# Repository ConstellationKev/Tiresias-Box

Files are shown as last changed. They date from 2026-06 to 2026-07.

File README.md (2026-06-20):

# Tiresias' Box

A portable, dynamic braille translator for both English and Chinese that incorporates an idea for changeable braille never been presented before. This is the first ever braille actuator cell that uses rotating CAM mechanisms to change the positions of the braille dots.
* Demo Video: [https://youtu.be/Fnp10YjDIxU?si=KQs606D453VQbDC9](https://youtu.be/Fnp10YjDIxU?si=KQs606D453VQbDC9)

Front  
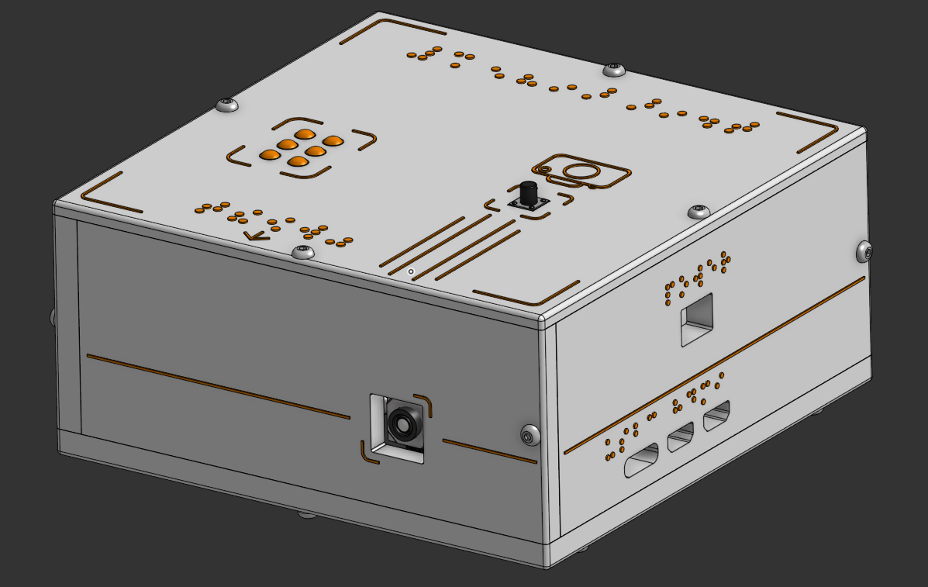
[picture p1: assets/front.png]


Back  
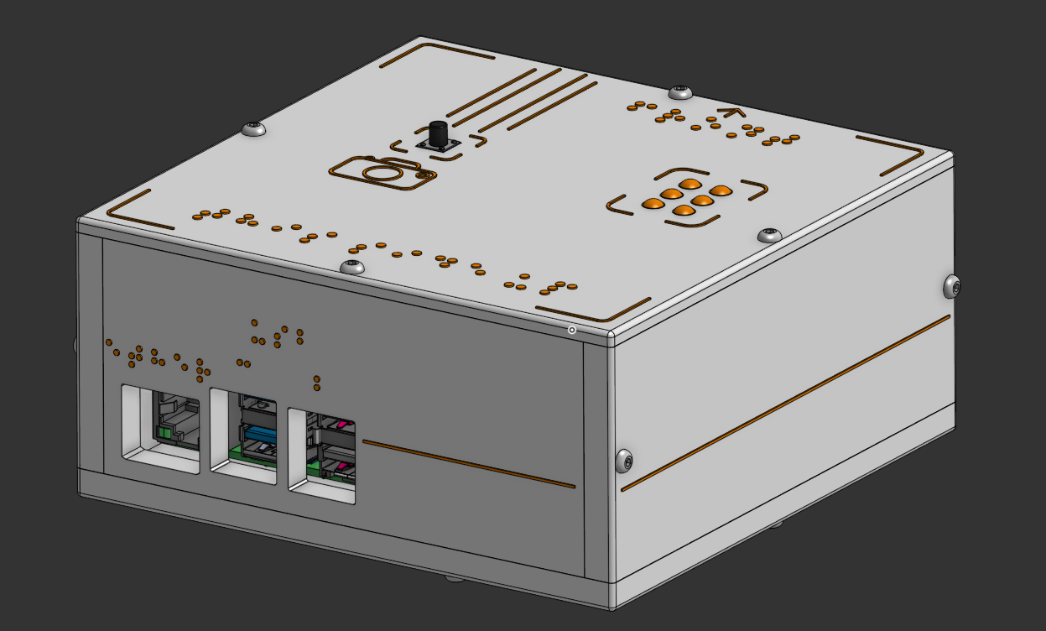
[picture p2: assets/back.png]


# Overview

This is a fun box that has a feature to take pictures of where its camera is pointing and then extracts the English or Chinese text it sees in real life to translate into braille in the braille area on top of the box. This box is only about 12 cm x 12 cm x 5.5 cm large and is very light. The white and orange design of the box was inspired by FRC 118 Robonauts, the team that got me into the white and orange design colors. The extremely easy assembly makes this a very beginner friendly project that even me, a complete beginner, could build with ease.

# Highlights

* **Custom Rotating CAM Braille Actuators**: The heart of this project, which are two custom made independent rotating CAMs stacked on top of each other which is able to change the orientations of the pins to be able to output every letter in the braille alphabet.  
* **Nicely-Scaled Braille Pins**: These small 3D printed custom pins are always in direct contact with the CAMs and are driven by nature’s most natural force, gravity. These pins are extremely light and gravity is all they need to be able to move with the CAM. They are also a good size to be felt with a single finger.  
* **Autofocus Raspberry Pi Camera Module 3**: Camera that does not require manual focusing and can take pictures of its surroundings in high detail and resolution to help with text extraction and analysis.  
* **Raspberry Pi 5**: The Raspberry Pi and the fact that all the mechanisms that drive that this project are connected to it makes this project very customizable. The Raspberry Pi allows for extremely fast live processing and analysis as well as file storage and servo control. Other people wanting to make this project can add onto the preexisting code as well as connect other mechanisms to widen the capabilities of this box.  
* **Blind Friendly** **Usage**: All of the ports and other important parts of the box are labeled with real braille which can be read by blind people. Although this box is not the most practical design currently, it is still able to be used completely by blind people.
* **Both Chinese Simplified And English Support**: This little box is able to both extract English text as well as Chinese Simplified characters and translating it to English, covering two of the biggest languages in the world.  

Custom braille CAM actuators  
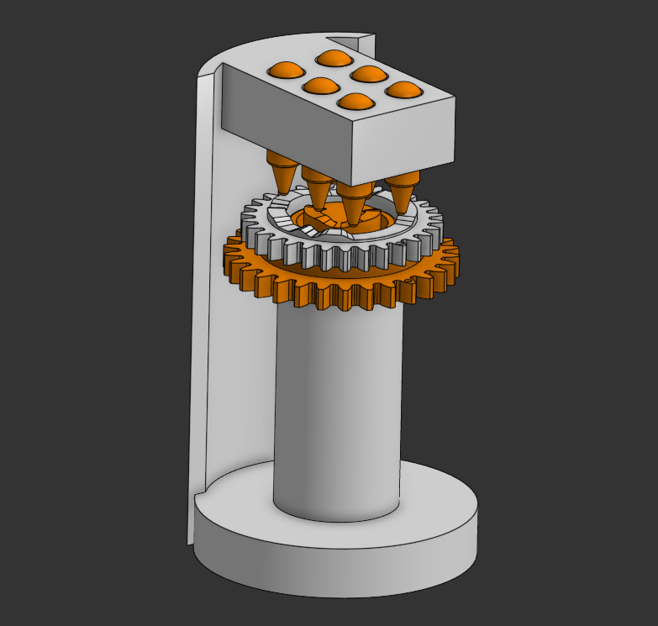
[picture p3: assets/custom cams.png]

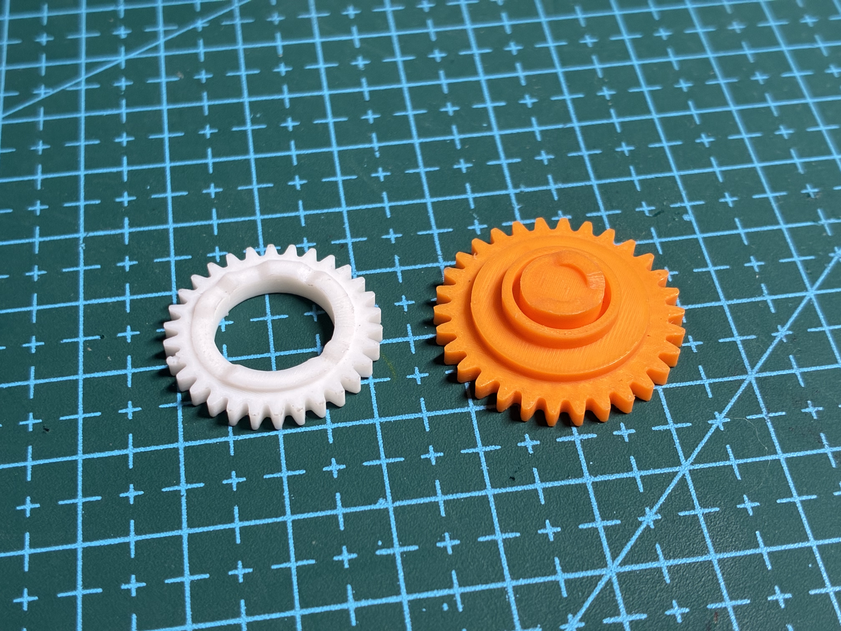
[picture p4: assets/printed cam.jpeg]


# Why?

Let’s first talk about why this is called Tiresias' Box. If you are a Greek mythology fanatic like I am, you would instantly recognize the all-knowing, blind prophet Tiresias. This person is an absolute legend and is one of the most knowledgeable Greek mythology characters. I wanted to create a project to help the blind as this disability should not be a limiting factor for their potential to do great things, just like Tiresias. 

This project helps solve the real world problem of blind people not being able to read words in the world, whether that is street signs, a restaurant menu, or something in the newspaper. It uses a camera and computer vision to restore their sight, translating the words they are unable to see into a format they are very familiar with, braille. Making this project as small as possible also helps take one step closer to this being a practical, portable device that people can bring wherever they go, actually helping them in the real world.

However, some people may have many questions about this project such as why not just use speakers? Personally, my answer to that is that speaking out words in the real world already exist and are more efficient than ever. Almost all phones have apps that can do this better than any personal project and they can even connect any external headphones to the phones.

Another question people may ask is how is this different from existing dynamic braille actuators? This is my unique approach to dynamic braille which incorporates CAM mechanisms to change the braille rather than some existing designs such as using a separate motor for every single braille dot or electromagnetic actuators. Some of the main goals that I hoped to accomplish is using as few motors as possible and making the braille dots move both smoothly but also stay rigidly in place when people’s fingers are moving over them and pressing down on them. Some electromagnetic designs are not strong enough to hold up the force of people’s fingers on the braille or it is not too energy efficient. I thought of a custom rotating CAM mechanism that essentially has rises and drops in the CAM that drives the pin's braille pins to move up and down. The braille pins are also in constant contact with the CAM due to their light weight and force due to gravity so they will have more than enough normal force to withstand people’s fingers. Additionally, the servos that drive these CAMs do not need to use any power to help keep the pins where they should be, they are already propped up by the CAM's geometry. Furthermore, I separated the CAMs into an inner and outer CAM which lessened the amount of motors to drive the braille down to two servos to control the movement of six pins. This is what makes this design different from all the current designs.

Lastly, I love computer vision. I always do the computer vision algorithms on my robotics team and I have always found its applications endless and all the different parts of it super intriguing. If I do a project, it would not be mine if it did not include any computer vision 🙂.

# How To Use

This project is extremely easy to use, only consisting of a button that you would need to press and the code ran from the Raspberry Pi. If you did the run script upon power up command from the software setup steps, this project would essentially be similar to any project you would find for sale. However, if you didn’t do that step, you would need to run the main.py file in the firmware folder in the Raspberry Pi.

Do these steps after you have properly assembled and set up the box please. They will not work otherwise.

1. Plug the USB-C power source into the Raspberry Pi through the USB-C port opening and the 5V power source into the PCA9685 through the opening to the top right of the USB-C opening.  
2. Boot up the Raspberry Pi and wait for about 5 seconds for the camera to start up and adjust to its surroundings and the braille to move to its initial positions, and you are ready to use it\!  
3. Press the button to take a picture of whatever is in front of it and the dynamic braille will automatically change depending on the letters that it sees. It will go in order from left to right to the letters/words it sees, first displaying the leftmost letter, then changing to the next letter, and so on until all the text is displayed. Each character will stay for about 2 seconds until the next one is displayed.  
4. After all the text is displayed and the braille is no longer changing, you will be able to take another photo of different text and it will show that text. No need to worry about memory of the photos as after each translation, the photos that you have taken will be deleted to save storage. 
5. Press and hold the button for about 3 seconds and the box will be able to toggle translate from Chinese to English or purely English for the photos that the user takes. The braille that is displayed will be in English. Press and hold the button to switch the detection model. The inital model will only extract English; the next toggle will be able to translate.
5. Press and hold the button for about 6 seconds and the code will stop and the camera will power off. Make sure you do this every time to ensure the code stops properly and the camera powers off nicely. Directly cutting the power may wear the Pi and the camera unnecessarily and is bad practice.  
6. After doing so, you can power off your Raspberry Pi and unplug the external power supplies.

Where the external power supplies should be plugged in  
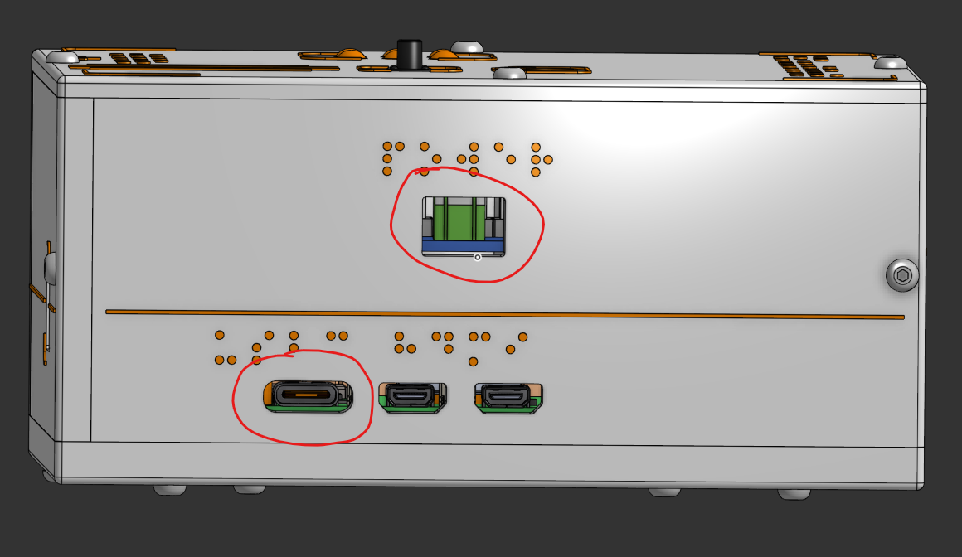
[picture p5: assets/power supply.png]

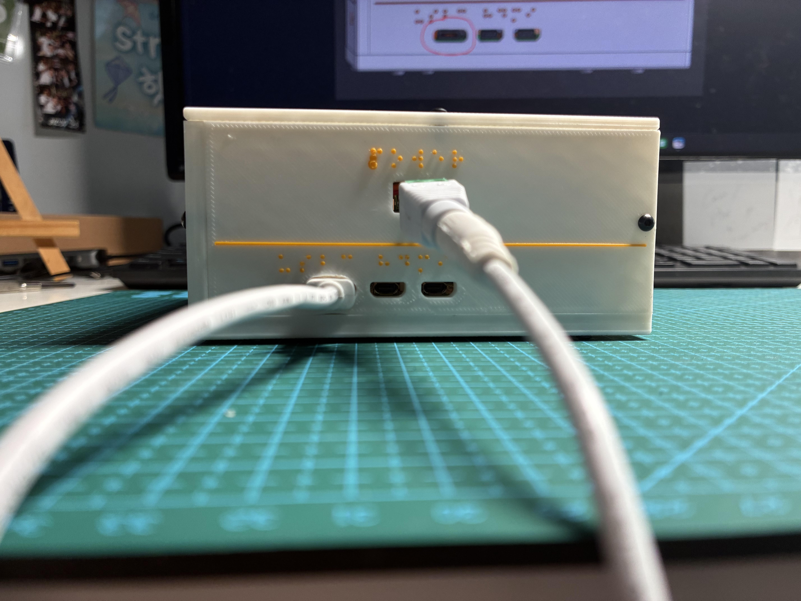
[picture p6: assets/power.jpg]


# Hardware

| Component | Notes |
| :---- | :---- |
| Raspberry Pi 5 | For running the code, storing files, live computer vision analysis, being the brain of the whole project. |
| Adafruit PCA9685 Servo Driver | Running servos separately of the Raspberry Pi to lessen its load and prevent the risk of frying the Pi due to the servos. |
| Raspberry Pi 27W USB-C PSU | For powering the Raspberry Pi |
| 5V 2A power supply | For powering the PCA9685 |
| Raspberry Pi Camera Module 3 Standard \- 12MP Autofocus | Autofocus camera that is able to take high resolution photos for efficient computer vision analysis. |
| SG90 9g Digital Micro Servo | To move the CAM mechanisms. |
| 6mm 2 Pin Panel PCB Momentary Tactile Tact Push Button | To control when to take pictures, change the braille, and turn off the code. |
| 16GB+ Micro SD Card | Store files and the Raspberry Pi OS. |

You can find more detailed buying links and prices of these components as well as other materials not listed here in the [Bill Of Materials](/BOM/BOM.csv) below.
|Material |Qty|Units |Buying Link (Accounts for quantity) |Cost (Accounts for shipping)|Notes |
|---|---|---|---|---|---|
|Raspberry Pi 5 4GB RAM |1  |Each  |https://www.microcenter.com/product/673712/raspberry-pi-5 |$109.99 |I can pay out of pocket for this if it is unable to be approved for funding.|
|Raspberry Pi Camera Module 3 Standard - 12MP Autofocus |1  |Each  |https://www.amazon.com/Raspberry-Pi-Camera-Module/dp/B0BRY6MVXL/ |$43.89 | |
|Raspberry Pi 5 FPC Camera Cable |1  |Each  |https://www.microcenter.com/product/671933/raspberry-pi-5-camera-cable-300mm |$2.99 | |
|Adafruit 16-Channel 12-bit PWM/Servo Driver - I2C interface - PCA9685|1  |Each  |https://www.microcenter.com/product/613661/adafruit-industries-16-channel-12-bit-pwm-servo-driver|$14.95 | |
|20 AWG Silicone Hookup Wires (2 Colors) |2  |Wires |https://www.amazon.com/Silicone-Electrical-Core-Flexible-Strands/dp/B0B9JCXN9M/ |$5.88 | |
|Female DC Power adapter - 2.1mm jack to screw terminal block |1  |Each  |https://www.amazon.com/ALITOVE-100-240V-Replacement-Security-Raspberry/dp/B0BVHQKNS6/ |$9.99 | |
|5V 2A (2000mA) switching power supply - UL Listed |1  |Each  |Same as above ^ |$0.00 |Included in above price |
|Raspberry Pi 27W USB-C PSU |1  |Each  |https://www.microcenter.com/product/671926/raspberry-pi-27w-usb-c-psu-white?src=raspberrypi |$11.99 | |
|6mm 2 Pin Panel PCB Momentary Tactile Tact Push Button |1  |Each  |https://www.amazon.com/MakerSpot-Momentary-Extension-Breadboard-Friendly/dp/B01J9KO7DC |$7.99 | |
|SG90 9g Digital Micro Servo |2  |Servos|https://www.amazon.com/Micro-Miuzei-Servos-Arduino-Airplane/dp/B0FJQZSFMS?th=1 |$8.44 | |
|M2.5 Screws + Nuts Kit |1  |Each  |https://www.amazon.com/binifiMux-280pcs-Button-Socket-Assortment/dp/B09CPDVYB7/ |$9.99 | |
|M2 Screws + Nuts Kit |1  |Each  |https://www.amazon.com/QOOSIKICC-Assortment-Socket-Washers-Machine/dp/B0DDXZH9L2/ |$7.58 | |
|Soldering Kit |1  |Each  |https://www.amazon.com/Soldering-soldering-solder-adjustable-temperature/dp/B09DY7CCW5/ |$9.99 |Self-sourced, I already own this so I don't need extra funding for this. |
|Jumper Wires F-F |4  |Wires |https://www.microcenter.com/product/618773/inland-30cm-40-pin-f-f-jumper-wire |$2.99 | |
|16GB Micro SD Card with Adapter |1  |Each  |https://www.amazon.com/SanDisk-Ultra-MicroSDHC-Memory-Adapter/dp/B00KNSAIVU/ |$26.89 |Self-sourced, I already own this so I don't need extra funding for this. |
|Base 3D Part |1  |Each  |N/A |$1.65 |Self-sourced, I already own this so I don't need extra funding for this. |
|Braille Pin 3D Part |6  |Each  |N/A |$0.06 |Self-sourced, I already own this so I don't need extra funding for this. |
|Close Wall 3D Part |1  |Each  |N/A |$0.44 |Self-sourced, I already own this so I don't need extra funding for this. |
|Far Wall 3D Part |1  |Each  |N/A |$0.44 |Self-sourced, I already own this so I don't need extra funding for this. |
|Inner Cam Servo Gear 3D Part |1  |Each  |N/A |$0.07 |Self-sourced, I already own this so I don't need extra funding for this. |
|Inner Cam 3D Part |1  |Each  |N/A |$0.04 |Self-sourced, I already own this so I don't need extra funding for this. |
|Left Wall 3D Part |1  |Each  |N/A |$0.45 |Self-sourced, I already own this so I don't need extra funding for this. |
|Long Spacer 3D Part |4  |Each  |N/A |$0.04 |Self-sourced, I already own this so I don't need extra funding for this. |
|Outer Cam Servo Gear 3D Part |1  |Each  |N/A |$0.05 |Self-sourced, I already own this so I don't need extra funding for this. |
|Outer Cam 3D Part |1  |Each  |N/A |$0.02 |Self-sourced, I already own this so I don't need extra funding for this. |
|Right Wall 3D Part |1  |Each  |N/A |$0.47 |Self-sourced, I already own this so I don't need extra funding for this. |
|Roof 3D Part |1  |Each  |N/A |$0.77 |Self-sourced, I already own this so I don't need extra funding for this. |
|Upper Mounting Plate 3D Part |1  |Each  |N/A |$0.13 |Self-sourced, I already own this so I don't need extra funding for this. |
|Taxes (in Fremont, California) |N/A|N/A |N/A |$28.51 |I don't need extra funding for this, I can pay this. |
| | | |Total Cost: |$306.69 | |
| | | |Note: Everything is bought with Amazon and Microcenter which has free shipping | | |

# About EasyOCR and Deep Translator

These are the two main Python libraries that I used in my project and are also integral parts of many other everyday applications. EasyOCR is a library that runs Optical Character Recognition which often built on neural networks to help detect text in real life, and then convert it to the string characters that we see on our computers. This software has been around for some time and is used for the text extraction for scanning documents on our phones, finding text in photos, and much more. In my project, the library EasyOCR is dircetly able to be used in Python and it utilizes PyTorch which is one of the biggest machine learning frameworks for Python currently. Every time the code runs, EasyOCR creates a model based on certain parameters to help you detect text. Due to the constraints for Raspberry Pi (yes, even this had constraints), my idea of being able to translate both English and Chinese using two different reader models was not feasible since a model consumes a lot of RAM each (we're saying from 1-3GB spikes) and I don't have much. Therefore, I was able to combine these two languages into a single model, as well as use a quantized model (using 8-bit integers for optimizing how much numerical precision the model outputs) to reduce the latency and improve the processing speed and efficiency. Since the Raspberry Pi is mainly using CPU for processing, the model also supports that and using a quanitized model helps with smaller RAM and CPU processing; it initially uses GPU and VRAM but Raspberry Pi does not support this. This model is essentially a neural network that runs every time for a image; downloading this model alone also takes up some storage and uses RAM, but it is less than actually running processing in the model. Well, if that isn't enough, let's introduce Deep Translator. This library allows us to use multiple different translation API clients such as Google Translate, which was used in this project. If there are any RAM concerns about this library, it does not do a lot of heavy lifting like the computer vision OCR pipelines above and it does use cloud clients which makes its processing even lighter. Therefore, its RAM usage is almost negligible and the RAM can be focused on running OCR. Both these libraries are integral parts of my project and it would not be possible without them. Please check out their documentation, they are genuinely so interesting and I hope you will find them useful in many of your future projects as well.
EasyOCR: [https://www.jaided.ai/easyocr/](https://www.jaided.ai/easyocr/), here's also the [github repo](https://github.com/JaidedAI/EasyOCR)
Deep Translator: [https://deep-translator.readthedocs.io/en/latest/](https://deep-translator.readthedocs.io/en/latest/)

# Assembly instructions

Make sure to finish the [software setup instructions](resources/software_setup.md) before continuing onto the [hardware setup instructions](resources/hardware_setup.md). You can find the same [wiring diagram](resources/wiring%20diagram.jpg) in the resources folder.   
Just to clarify a few things, for the PCA9685, the ground wire goes to the ground pin on the Raspberry Pi, the SCL wire goes to the SCL pin, the SDA wires goes to the SDA pin, and the VCC wire goes to the 3.3v pin.  
The button’s wires can be routed in any way to the GPIO5 and the ground pin next to it.

Wiring Diagram  
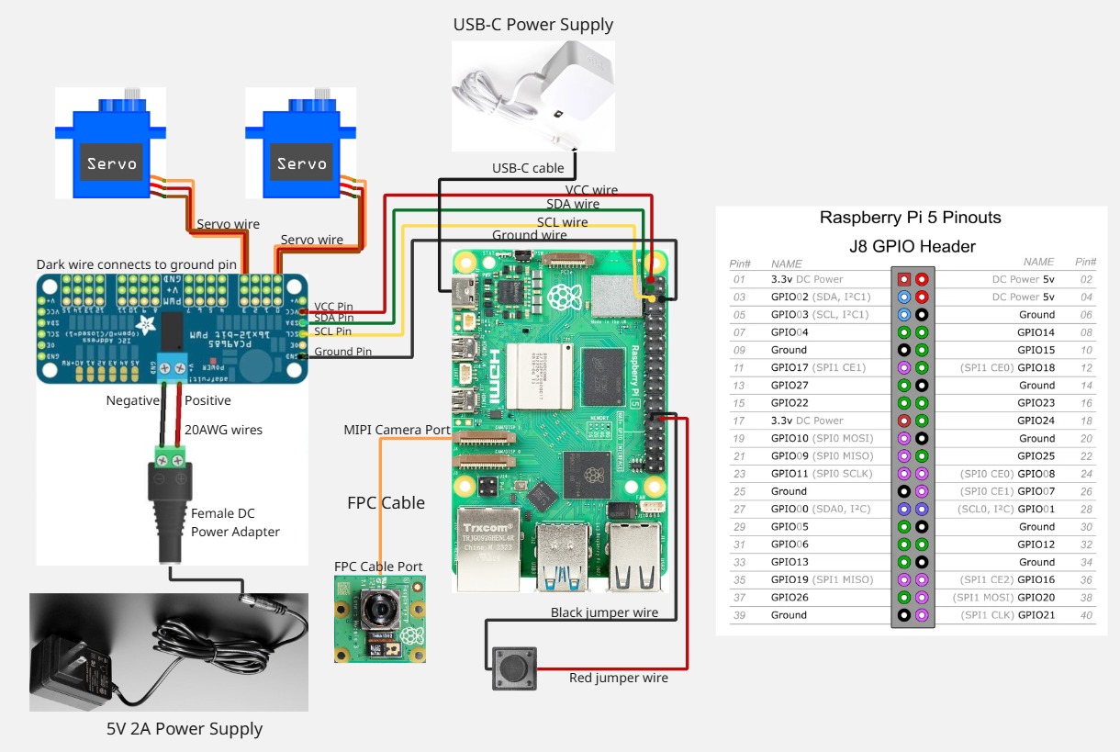
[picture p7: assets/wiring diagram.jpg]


# V1 Testing

Testing for proof of concept:


# Credits

All 3D Models cadded with Onshape.

The incredible YouTube videos that taught me along the way:

* [https://www.youtube.com/watch?v=GwpSpOwvx9Y\&t=1s](https://www.youtube.com/watch?v=GwpSpOwvx9Y&t=1s)  
* [https://www.youtube.com/watch?v=-x2EEIUMm6A](https://www.youtube.com/watch?v=-x2EEIUMm6A)  
* [https://www.youtube.com/watch?v=XPpw5P6AoEA](https://www.youtube.com/watch?v=XPpw5P6AoEA)  
* [https://www.youtube.com/watch?v=w-4V\_q8XWtk](https://www.youtube.com/watch?v=w-4V_q8XWtk)  
* [https://www.youtube.com/watch?v=Gl9HS7-H0mI](https://www.youtube.com/watch?v=Gl9HS7-H0mI)

# The Future

Currently, my project requires the box to be upright since it relies on the pin’s light weight and gravity for the CAM to move the braille pins. The pins are also able to be switched out easily by just plucking them out of the holes. However, in the future, I would want the box to be able to work in every single orientation, even when upside down. This made me think to either use very small springs or even make them magnetic to the CAM. I have researched these ideas and the small springs were very difficult to find for my tiny pins and the magnetic CAM is not possible since I only have a plastic 3D printer and no CNC or laser cutter.

I also would like the whole box to be even smaller and compact to make it even more portable and practical for every day use.

I would also like to make the CAM and pins even smoother. Right now, even using a 0.2 mm nozzle and the thinnest slicer settings, there are still layer lines on my prints. I want to eliminate those entirely in the future using some of those more advanced ways to get these custom 3D parts.

# Contact

* Discord: eclipse\_c  
* Email: kevinkunzhong@gmail.com

# Zine
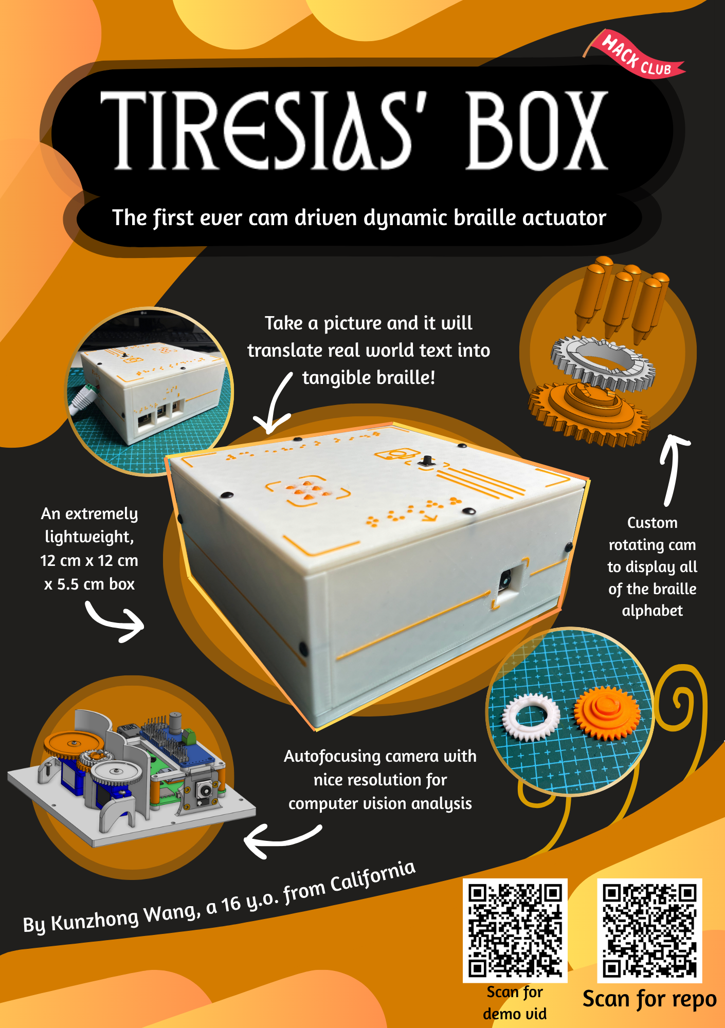
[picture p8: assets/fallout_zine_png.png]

The [PDF version](resources/fallout%20project%20zine.pdf) can be found in the resources folder.

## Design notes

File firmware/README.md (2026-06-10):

# Tuning Positions
A lot of this code requires to manually tune positions of the servos based on the braille pin positions and the gear positions. I have put everything that requires to be tuned as a value of 0 for now and they will be tuned when parts arrive for actual building.

Tuning only needs to be done once as the servo models will be the same for the project so other people building this project will have the same degrees of rotation. The hardware setup python file will set the servos to the inital positions so that each similar project to this will be set up the same way. So, this code and to-be-tuned postions will be able to be used for any project like this one.

Additionally, other things that also need to be tuned are the delay and timing thresholds for the servo movements

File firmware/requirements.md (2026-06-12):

# Requirements
## Libraries Required to Run Code:
1. `adafruit_servokit`
    - Import by typing this command into Raspberry Pi Terminal: `sudo pip3 install adafruit-circuitpython-servokit`
    - Command to fix externally-managed-environment error: `sudo rm /usr/lib/python3.11/EXTERNALLY-MANAGED`
2. `time`
3. `easyocr`
    - Import by typing this command into Raspberry Pi Terminal: `sudo pip3 install easyocr`
    - Command to fix externally-managed-environment error: `sudo rm /usr/lib/python3.11/EXTERNALLY-MANAGED`
4. `picamera2`
    - Included with the Raspberry Pi OS
5. `libcamera`
    - Included with the Rapsberry Pi OS
6. `os`
7. `gpiozero`
8. `deep_translator`
    - Import by typing this command into Raspberry Pi Terminal: `sudo pip3 install deep-translator`

## Enough Storage For Running things
Make sure your SD card can hold your Raspberry Pi OS as well as be able to hold the code and image files. The OS is about 8GB so make sure to find an SD card to be able to do other things as well. Anything above 8GB should be fine.

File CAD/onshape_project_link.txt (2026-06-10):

https://cad.onshape.com/documents/8ab90068d8e5494ca445e30f/w/5666b0c0f4cc86aaf66cce07/e/73d03172aee4f037fc1a40dc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

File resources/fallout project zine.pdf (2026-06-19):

## The first ever cam driven dynamic braille actuator

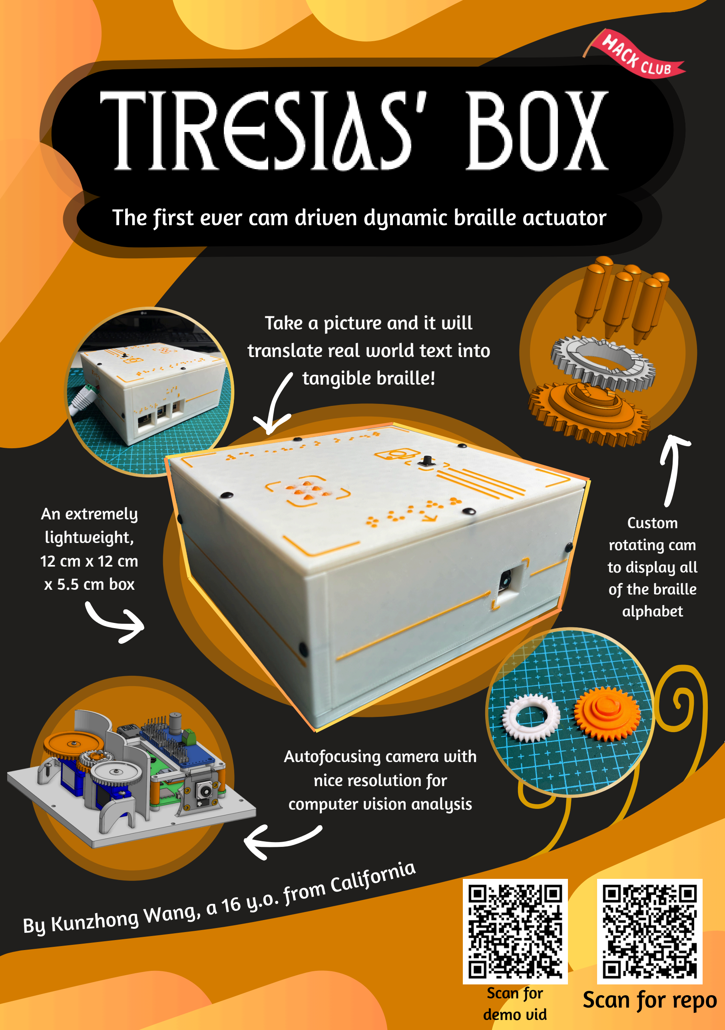
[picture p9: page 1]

Take a picture and it will translate real world text into tangible braille!

## Scan for repo

### By Kunzhong Wang, a 16 y.o. from California

Autofocusing camera with
nice resolution for
computer vision analysis

An extremely
lightweight,

### 12 cm x 12 cm

x 5.5 cm box

Custom
rotating cam
to display all
of the braille
alphabet

Scan for
demo vid

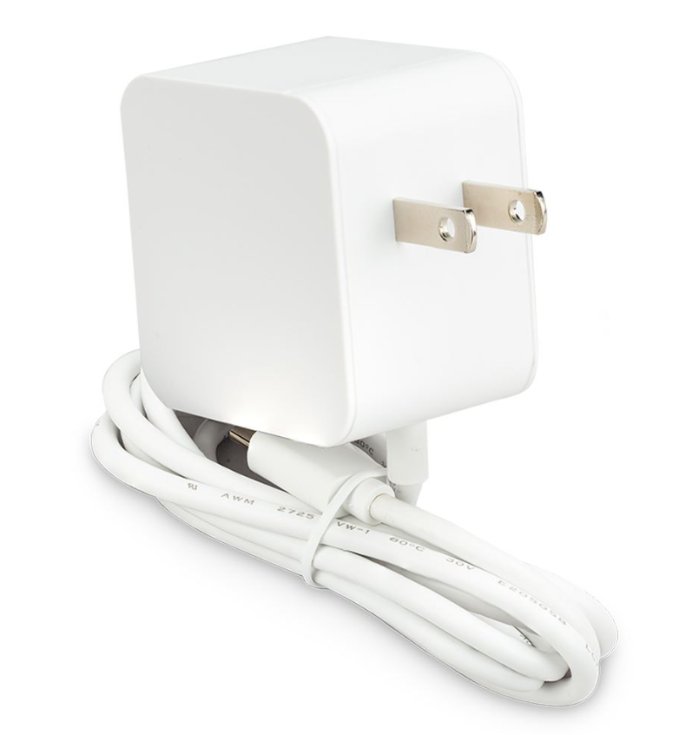
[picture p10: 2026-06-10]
resources/reference images/white USB-C power supply.png

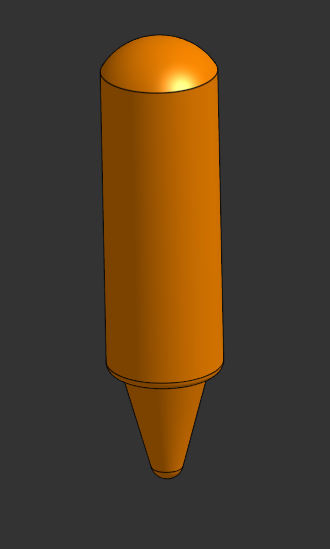
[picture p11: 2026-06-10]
resources/reference images/braille pin.png

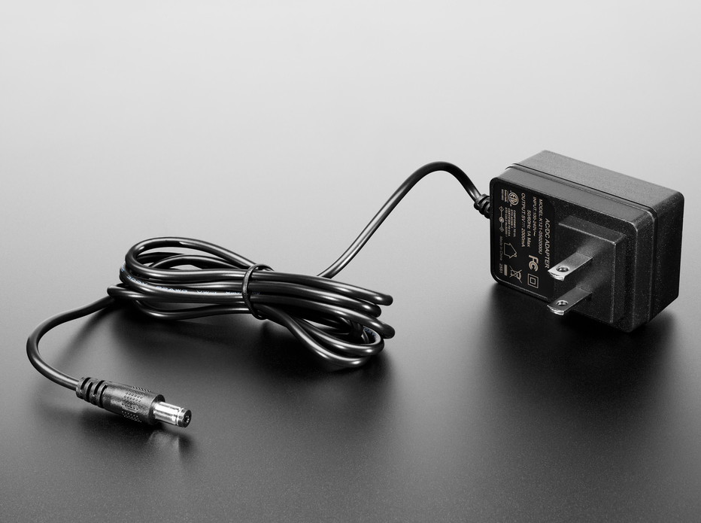
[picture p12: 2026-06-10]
resources/reference images/black 5V power supply.png

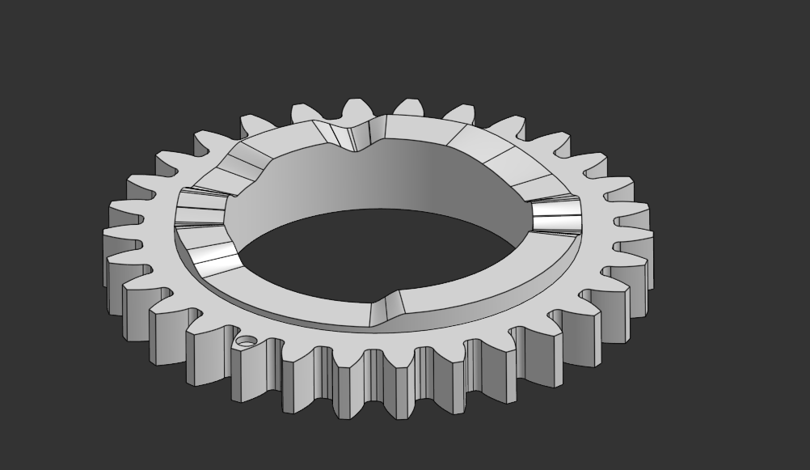
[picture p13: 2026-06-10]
resources/reference images/outer cam.png

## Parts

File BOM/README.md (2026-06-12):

# BOM Notes
## Why Certain Parts?
1. I chose the Raspberry Pi 5 because it only costs $9 more than the Raspberry Pi 4 and is the newest version. 4GB RAM was due to the research I did that asked for live computer vision analysis using tools like OpenCV and OCR. It was slightly on the lower end of the RAM many people suggested but it should be fine to run my CV applications, as well as all the other things in the code. I also read the docs and researched about Raspberry Pi Zero 2 W but their biggest bottleneck is the RAM and I need more RAM to run OCR, file managing, controlling servos, running the script, all live. I don't know what else I can use. I also don't know how to make my own PCB (but will definitately learn in the near future!) and this was suggested as the most beginner friendly way to manage and operate my project since it is essentially like a computer which I can code on. If this cannot be approved for funding, I am willing to pay out of pocket since changing will require a ton of tweaking for the entire project and just a lot of hours.
- Note: Here is a website I used for my research on using easyocr / OCR with my project and I tried to make things as cheap as possible for myself. https://www.llamaindex.ai/glossary/what-is-easyocr. The requirements are found in the System Requirements and Dependencies section. Raspberry Pi 5 with the minimum 4GB RAM is one of the few options that work within these specs.
- Please also read the About EasyOCR and Deep Translate section in the main [README](../README.md)
2. The Raspberry Pi Camera Module 3 was chosen because of its relatively high image quality as well as ability to autofocus. My project requires the camera to be able to detect and analyze text that appears in real life so having higher quality is a must. Autofocus is also a great feature since the people should not need to manually focus the camera; I also don't know how they would since they are blind.
3. The Adafruit PCA9685 is needed since many people suggested it is not good practice to run servos as well as a camera and doing live analysis using scripts on the Raspberry Pi all at once. This allows servos to run separately and not put any load on the Pi, which lowers the risk of frying it.
4. The push button was chosen since most buttons I found are for breadboards and this one can be directly plugged into the Raspberry Pi which helps a beginner a lot.

## Why Certain Buy Links?
Most of these buy links are to materials that are more in quantity that I need but I genuinely tried to find the least and cheapest options online.
1. The 20 AWG wires on Amazon were the least length I could find online since most vendors sell by tons of feet but I don't need that much. This is the least I can find for two colored wires.
2. The Push Button also comes in a pack of 5 on Amazon but I could not find any cheaper and singular selling buttons online. Most buttons I find either come in even larger packs or do not contain two wires to connect to the Raspberry Pi. 5 pack is least I can find.
3. The SG90 servos on Amazon are the digital ones that I need for precise movement but the least pack I can find them in is a pack of 3 when I only need 2. I tried finding packs of two online for digital servos but they are either very poorly reviewed or even more expensive than this 3 pack or they don't mention that they are digital.
4. The same situation for the jumper wires as the 20AWG hookup wires.
5. For the screws + nuts kits, I don't have any srews and stuff at home so this is the first time getting these kits. Other kits online are are either too expensive or do not contain the lengths of screws I need. This is also like an investment for my future projects so I don't need to buy any more screws.

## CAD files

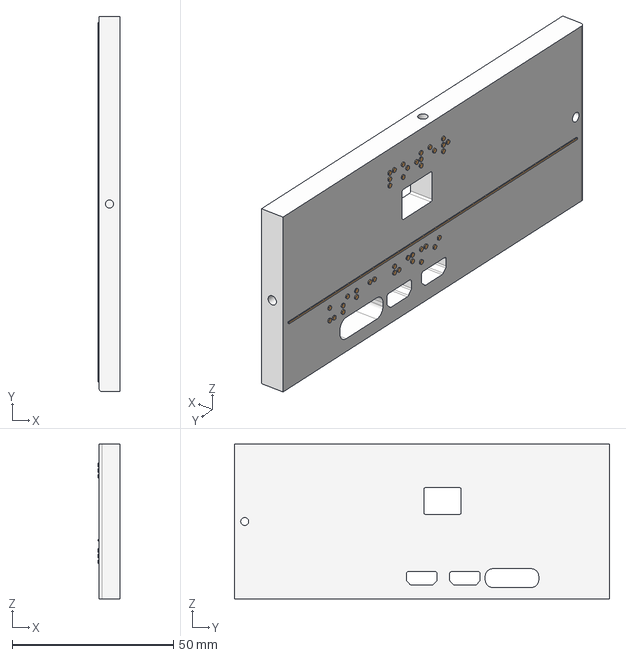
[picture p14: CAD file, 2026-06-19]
CAD/STEPs/left wall.step
6.80 x 116.5 x 48.1 mm

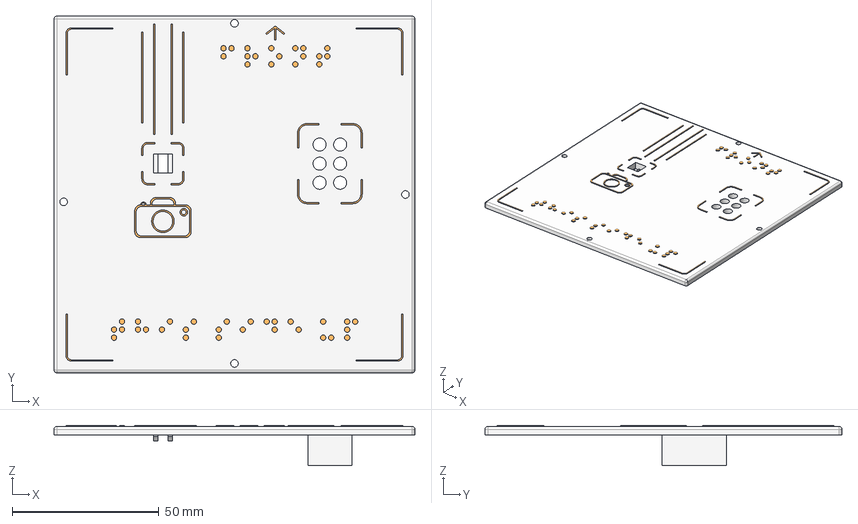
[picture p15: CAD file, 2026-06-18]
CAD/STEPs/roof.step
122.8 x 121.5 x 13.6 mm

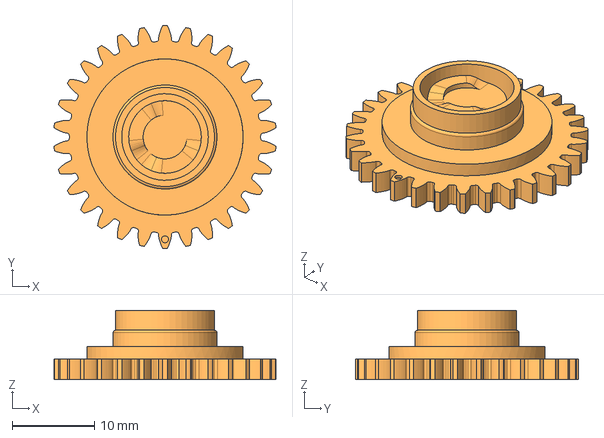
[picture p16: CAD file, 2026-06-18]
CAD/STEPs/inner cam.step
27.0 x 27.1 x 8.40 mm

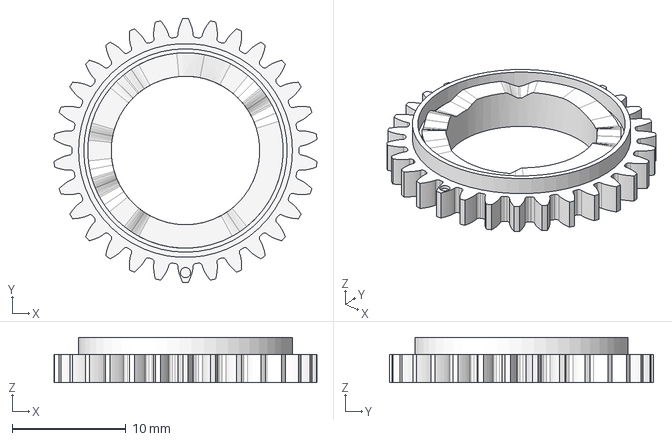
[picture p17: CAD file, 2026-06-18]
CAD/STEPs/outer cam.step
23.1 x 23.2 x 4.00 mm

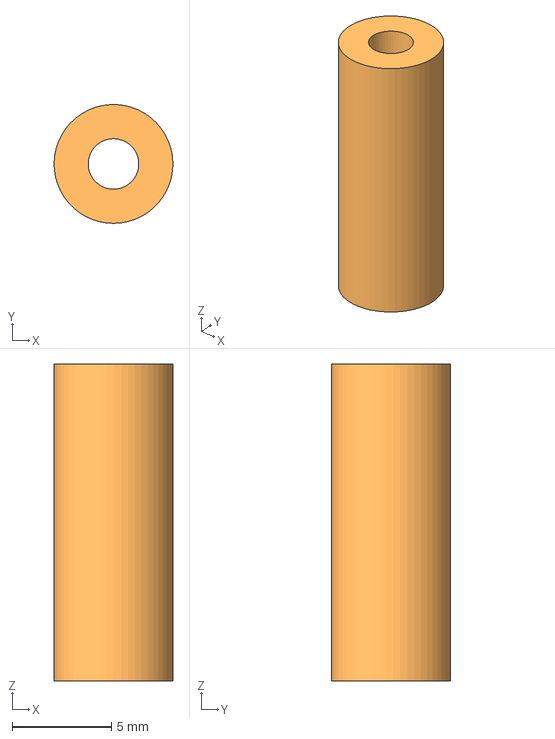
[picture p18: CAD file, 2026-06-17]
CAD/STEPs/long spacer 2.step
6.00 x 5.99 x 16.0 mm

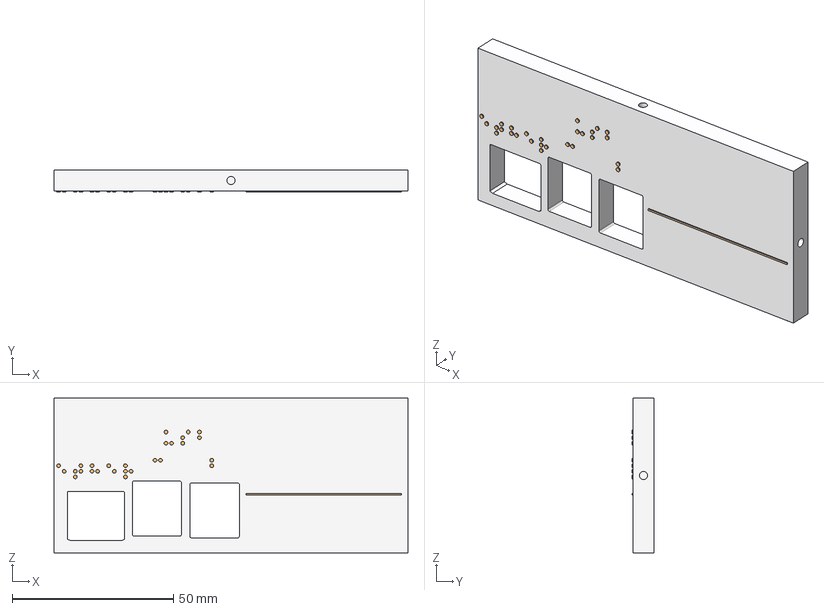
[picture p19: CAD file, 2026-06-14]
CAD/STEPs/close wall.step
109.8 x 6.80 x 48.1 mm

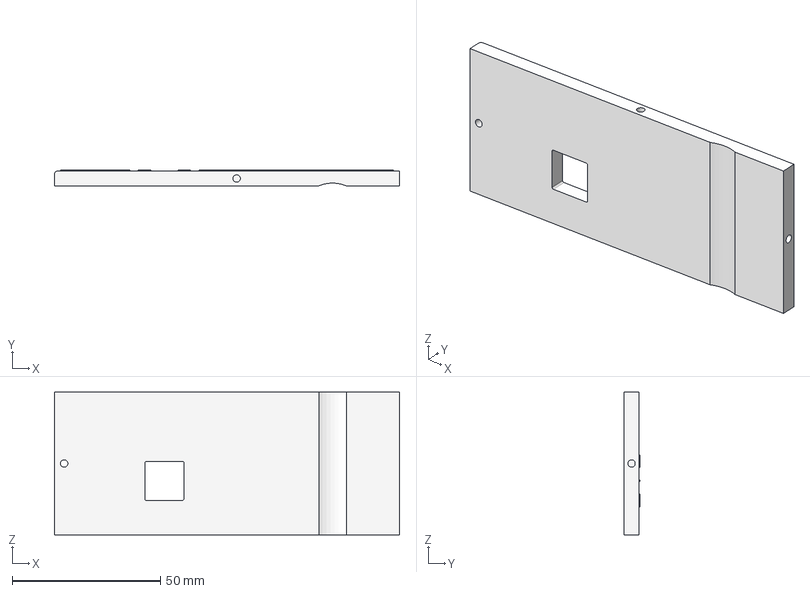
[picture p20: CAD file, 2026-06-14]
CAD/STEPs/far wall.step
116.3 x 5.30 x 48.1 mm

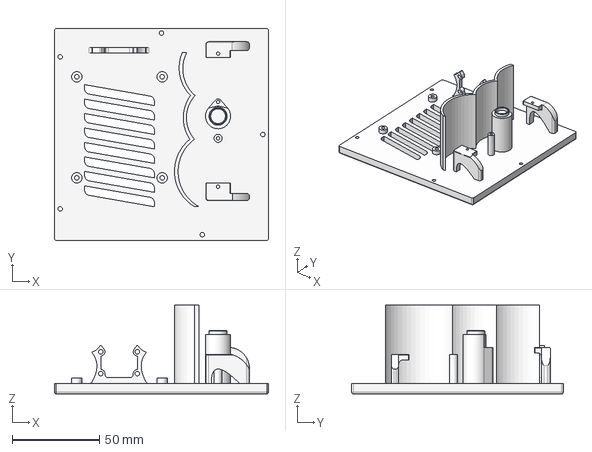
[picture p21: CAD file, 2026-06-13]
CAD/STEPs/base.step
122.8 x 121.5 x 51.0 mm

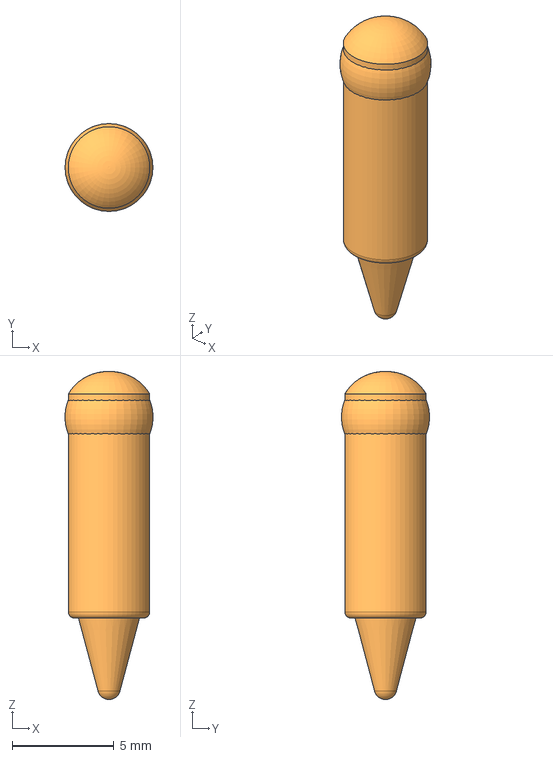
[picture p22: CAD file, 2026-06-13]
CAD/STEPs/braille pin 3.step
4.32 x 4.32 x 16.1 mm

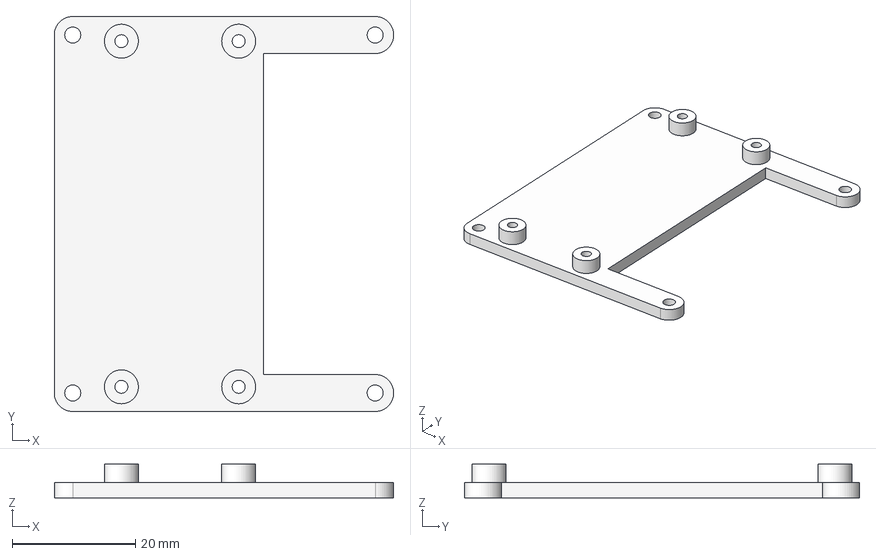
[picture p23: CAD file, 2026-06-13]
CAD/STEPs/upper mounting plate.step
55.0 x 64.0 x 5.50 mm

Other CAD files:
CAD/STEPs/long spacer 4.step
CAD/STEPs/long spacer 1.step
CAD/STEPs/long spacer 3.step
CAD/STEPs/right wall.step
CAD/STEPs/braille pin 5.step
CAD/STEPs/braille pin 1.step
CAD/STEPs/braille pin 6.step
CAD/STEPs/braille pin 4.step
CAD/STEPs/braille pin 2.step
CAD/STEPs/inner cam servo gear.step
CAD/STEPs/outer cam servo gear.step

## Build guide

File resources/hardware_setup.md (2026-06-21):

# Hardware Setup
If you haven't already, please set up the Rapsberry Pi 5 software and OS first before doing the hardware setup. This can be found in the [software setup](software_setup.md) file.
PLEASE REFER TO THIS WIRING DIAGRAM AS YOU PROCEED:

These hardware steps are assuming you have everything that the BOM requires, including 3D printed parts using the STEP files in the CAD folder. Also refer to the [BOM](../BOM/BOM.csv) which will contain everything you will need to assemble this project.

## Starting to Putting Everything Together (Leave Gears to the End)
1. First, print out the 3D file for the base of this box, as well as all of the other required 3D printed parts included. I recommend 10% infill and gyroid infill pattern, with a 0.4 nozzle, 0.12mm High Quality @BBL A1 setting.
2. Take your base and we will first start with the Raspberry Pi
3. Place your Raspberry Pi onto the 4 screw holes with the USB-C port facing away from the curvy wall.
4. Take your 4 long spacers and put them respectively onto the 4 holes on the Raspberry Pi.
5. Use M2.5 16mm screws to screw the Raspberry Pi and the 4 spacers from below the base.
6. Attach your Raspberry Pi Camera Module 3 to the camera mount, the one with holes facing horizontally, using M2 8mm screws and nuts on the back.
7. Connect your Raspberry Pi 5 FPC Camera Cable, with the wider end into the camera and the thinner end into the Pi's camera port, aka the closest MIPI connector.
8. Take the 3D printed upper mounting plate for the PCA9685 and place it on top of the four long spacers, making sure the opened up part is facing the curvy wall.
9. Make sure to tuck the camera's FPC cable nice and snug under the plate so that it doesn't block any of the header pins on the Raspberry Pi.
10. Attach the top plate on by screwing in M2.5 5mm screws into the spacers.

## Setting Up PCA9685
1. Take your PCA9685 board as well as the header pins and the terminal block that it comes with and place the smaller ends into their designated holes in the board.
2. Use your soldering kit and then solder the header pins and the terminal block onto the board.
3. Next, use M2 10mm screws and nuts to screw the PCA9685 into the upper mounting board.
4. Then, take your female to female jumper wires and plug them into the GROUND, SCL, SDA, and VCC header pins on the PCA9685.
5. Connect these to the corresponding header pins on the Raspberry Pi. The VCC wire should go to the 5V pin on the Raspberry Pi. Everything else goes to the same name.

Refer to these YouTube videos if you are confused, they helped me a ton: https://www.youtube.com/watch?v=-x2EEIUMm6A&t=274s and https://www.youtube.com/watch?v=GwpSpOwvx9Y

## Almost Done Putting Everything Together
1. Take your two servos and then mount them onto the two servo mounting areas on the other side of the wall. The servo wires should be facing outwards.
2. Screw in the servos with the M2 8mm screws that they come with.
3. Take the servo wires and then plug them into the servo pins on the PCA9685. Make sure the colors match up with black to black, orange to orange, so on. Plug the lower servo into the 0 port and plug the higher servo into the 3 port.

## External power supply
1. Take the 20AWG wires and then cut and strip them to however long you want them to be and then insert them into the terminal block onto the PCA9685.
2. Take the other end and insert it into the Female DC power adapter. You need to screw in the screws a bit to keep the wires in place for both.
3. MAKE SURE THE WIRES ARE CORRECTLY WIRED, positive goes to positive and negative goes to negative. Any mix up will potentially fry your entire project. Red is usually positive.
4. Plug in the 5V power supply into a wall socket and the other end into the female DC power adapter.
5. Plug in the USB-C power supply into a wall socket and the other end into the Raspberry Pi.

Should look something like this right now
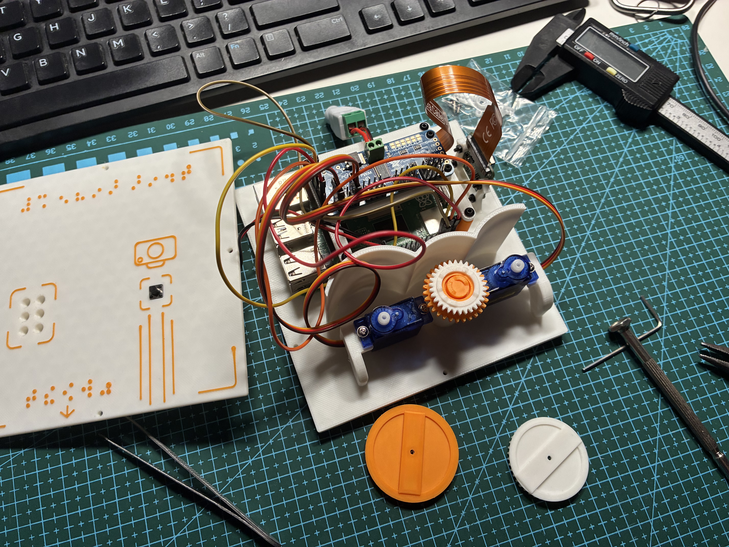
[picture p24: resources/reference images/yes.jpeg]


## Gears
1. Plug your Raspberry Pi into a monitory, since you need to run code.
2. Run hardware_setup.py and then make sure to not touch the servo splines or move them after the code is ran.
3. Place the inner orange CAM on the bottom first, onto the indent for it. Locate the small dot on the gear and make sure it faces away from the direction the camera is pointing.
4. Place the double-sided servo horns on each of the servos, putting one of the sides as close to the normal as possible but not entirely vertical
5. Place the orange servo gear onto the lower servo's horn, making sure the gear lines up well with the CAM gear. Make sure not to move the CAM gear. Adjust the servo gear based on it. Try to make the rubbing between the top og the servo gear and the CAM as less as possible.
6. Then, place the white outer CAM on top of the orange CAM, with the dot facing in the same orientation. 
7. Place the white servo gear onto the higher servo's horn. Do the same as the other one.
8. Use the servo srews that they provided and screw the servo gears onto the servo horns, onto the servo.
9. No screws are needed for the CAMs, they are held in place by the servo gears as well as each other.
10. Unplug the two external power supplies from the PCA9685 and Raspberry Pi.

## Roof and Walls and Button
1. Although the gears should be in place fairly snug, try not to flip the box upside down or shake it violently. It is not meant to be shaken.
2. Now that the base and everything else is set up, screw in the walls first using M2.5 10mm screws. The holes should line up with the ports on the Rapsberry Pi / the camera hole.
3. Take your roof and then wire the button wires through the button hole on the top.
4. Take your button wires and plug the button into the Raspberry Pi, one into a ground pin and the other in GPIO pin 5.
5. Hot glue your button onto the roof, or you can use any other type of binding method, or just leave it. The box isnt supposed to be moved around anyways and the mount for the button should be very snug such that it will be decently stuck in there. Gluing it just for your sanity lol.
6. Screw in the roof using M2.5 10mm screws.
7. Finally, place the 6 braille pins into the 6 holes on the top of the roof. Do not push them in, simply let them drop in.

You are done! Make sure to keep the box mostly upright when using to keep the pins from falling out (which is unlikely but only if you turn it fully upside down).


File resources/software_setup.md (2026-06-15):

# Software Setup
This setup guide should be completed first before the hardware setup guide.

## Raspberry Pi Imager
1. Follow this link to download the Raspberry Pi Imager that is needed to start your setup for the Raspberry Pi 5: https://www.raspberrypi.com/software/ 
2. After downloading the imager, select the device as Raspberry Pi 5, operating system as the 64-bit one, and then the storage device as your micro SD card you have plugged into your computer. 
3. After you reach the next popup, click on edit settings when it asks you to apply OS customization.
4. Afterwards, you can set a username and password if you like, and then also make sure to configure wireless LAN to connect you Pi to your house wifi.
5. Hit save and then write for it to write its OS onto your micro SD card.
6. After you are done, you can remove the card and plug it into your Raspberry Pi 5.

## Using the Raspberry Pi
1. After doing the OS setup, you can now use your Pi.
2. To do so, you can use an external monitor and use an HDMI cable to connect your Pi to your monitor and use it like an ordinary PC.
3. Or, you can control you Pi remotely using RPI Connect which you can find the tutorial here to use: https://www.youtube.com/watch?v=ZbadI2Vloh4, this is very well explained tutorial.

## Transferring Code and Firmware
1. After setting up the OS for the Raspberry Pi, you can download the code and firmware files from this github, which should all be under the firmware folder. 
2. Transfer the code files from your computer onto a USB drive and then plug that USB drive into one of the the Pi’s USB ports.
3. Open the Pi’s files manager and copy all of the needed code into the Pi’s “home” directory.

## Using Adafruit PCA9685 Servo Driver
1. This project requires an Adafruit PCA9685 Servo Driver which helps powers servos without having to put load onto the Raspberry Pi
2. Go to your terminal in the Raspberry Pi and type in this command: `sudo pip3 install adafruit-circuitpython-servokit`
3. If an "externally managed" error comes up, type in this command: `sudo rm /usr/lib/python3.13/EXTERNALLY-MANAGED`
4. This should download the library necessary for the code to run properly.
5. Refer to this documentation is anything is unclear: https://docs.circuitpython.org/projects/servokit/en/latest/

## Installing Libraries
1. Go to you Raspberry Pi terminal (which you should have open already from the preivous steps)
2. Install easyocr: `sudo pip3 install easyocr`
  However, oftentimes you will encounter an error where it says it runs out of space. In that case, you will need to follow these steps:
    - Run command: `mkdir -p ~/pip_tmp` to create a temporary folder in the main drive with a lot of space to download easyocr instead of using the RAM drive
    - Run command: `TMPDIR=~/pip_tmp pip install easyocr` to install it on the main drive
    - Run command: `rm -rf ~/pip_tmp` to remove the temporary folder used to download it to save space. Don't worry, the library is already installed and this won't affect that. 
4. Install deep_translator: `sudo pip3 install deep-translator`

## Code Running Upon Power On
1. This is optional but you can run the code as soon as the Raspberry Pi is powered on, to give a more authentic feel to the project, making it seem like its a real product.
2. Open the terminal in the Raspberry Pi and then type in: `sudo crontab -e`
3. Then, type 1 if it’s asking to select an editor.
4. Type in the command: `@reboot python3 /home/pi/Desktop/main.py &`
5. The above really depends on where you put your code files so you can change it accordingly. This assumes you have it all on your Desktop but you would likely have them in the firmware folder still.

## More: Raspberry Pi Camera
You can go into the terminal and type in `rpicam-hello -t 0` to get a live camera feed. You do need to close the window to stop it. Do this after you have attached your camera.

## Huge Thanks
I want to thank these YouTube videos which were an insane help to me when creating this project, they explained things so well and allowed to be get a good grasp despite being a complete beginner. 
Please refer to these videos if my explanations were unclear in any way, they are amazing.
https://www.youtube.com/watch?v=-x2EEIUMm6A 
https://www.youtube.com/watch?v=w-4V_q8XWtk 
https://www.youtube.com/watch?v=Gl9HS7-H0mI
https://www.youtube.com/watch?v=-x2EEIUMm6A

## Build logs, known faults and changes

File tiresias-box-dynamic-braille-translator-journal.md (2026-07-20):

# Tiresias' Box (Dynamic Braille Translator) — Journal Export

- Exported at: 2026-07-20T18:35:10Z
- Project ID: 2388
- Entries: 15

## Entry 1
- ID: 11321
- Author: kevinkunzhong
- Created At: 2026-06-03T05:54:26Z

### Content

Today I began my journey creating my dynamic braille translator. I used Onshape to design a single braille cell, which consists of 6 pegs that will eventually be controlled by a CAM to make them move up and down; each cell will be its own letter. In real life, I got out a ruler and figured out the approximate dimensions of each braille cell, which is about 15mm x 22mm. I created the outer casing and then the inside pins, since they need to be moving around in the casing.
Screenshot 2026-06-02 220050.png
This is a bit larger than conventional braille cells but it is still relatively small and also big enough so it will work well with a CAM. After creating temporary tolerances for the pegs as well as their design, with the bump on the top and part of it sticking downwards which will be in contact with the CAM.

Screenshot 2026-06-02 222305.png
I chose the pegs to take on this shape since the top is where the people will feel it, so a nice smooth bump will be great. I tapered the bottom down a little bit so that it will fit well with the CAM. The smaller the bottom is, the more intricate it can be with the CAM and thus have more positions to get to / more accurate. I also made the bottom rounded so when it does rotate with the CAM, it will be smoother.

Screenshot 2026-06-02 223451.png
I also figured out how to use the linear pattern tool, which I have never used before which is very cool and it allowed me to multiply one pin into 6 and fit them into my casing without having to re-cad the pins over and over again.

Screenshot 2026-06-02 222620.png
After creating the casing and the pins, I started creating the rotating CAMs. I didn’t make the up and down pattern of the CAM yet but I created a general location of where it will be.

I overall goal is to achieve dynamic braille while using the LEAST amount of electronic possible. Of course, using a servo for EVERY SINGLE pin would be soooo excessive (and expensive). Therefore, I thought of using a rotating CAM which can be powered by one servo only, but can cause the pins to be in multiple orientations. This not only saves servos, but also allows the pins to rest on something stable, giving it the normal force it needs when people feel it from above. However, CAMs are annoying and you have to map it out very accurately for each orientation. To make things simpler for myself, I separated the rotation wheels into an inner and outer one to make the CAM patterns separate into two separate parts, so that it is easier (relatively). I haven’t thought of using two servos or still using one but a shifting mechanism to move from outer to inner CAMs.

This leads me to actually mapping out the CAM shape which took FOREVER. 

Screenshot 2026-06-02 210157.png
I first found an image of the braille alphabet online and then mapped out all of the patterns and groupings of dots in every single letter. I grouped the dots by pair; top, middle, and bottom. Firstly, I delt with the inner CAM and since theres only two pins, it was very easy. You can either have up up, down down, up down, or down up, which was absolutely no problem for the CAM.
The nightmare began with the outer CAM. I took a screenshot and put approximate positions the 4 pins may be located at and then spaced them out somewhat evenly. This way, I can figure out what positions I can use for my CAM. I also figured out that for the top two and bottom pins, there are only 9 different combinations. So all I needed to do was map out the 9 orientations onto the outer CAM. Easier said than done. 

Screenshot 2026-06-02 215937.png
After about more than an hour of trial and error (yes that is how I figured out this CAM pattern) I finally decoded the positions the CAM needs to be at for the 9 orientations. It only took re-sizing the under portion of the pins to fit more positions and a pack of gushers.
So of course it was not blindly mapping. I tried my best to use as less circles as possible and reuse circles if I can. This is because I have very limited room and I cannot keep on shrinking the bottom side since it is already very small. For example, There are multiple cases where the bottom two are both down so I can just do down down and then instead of adding another pair, I just simply use a down from the previous one and add one down, saving one circle. I kept on doing this, and finally came up with this. I am genuinely so proud of myself for this, this was probably the most complicated CAM I’ve mapped despite it being only ups and downs. And this is where I stopped for today. 
TLDR: I did a rough CAD of my braille cells and mapped out the shape of my CAMs.

### Recording Links

- https://lookout.hackclub.com/api/media/2ff125fc-58fb-4db9-b666-54302c8e27e4/video.mp4

## Entry 2
- ID: 11553
- Author: kevinkunzhong
- Created At: 2026-06-04T06:28:12Z

### Content

Today I worked on actually designing the physical CAMs. Previously, I used an online whiteboard software to manually create the circles and map them out so I also did so in Onshape just for reference as well. This allowed me to better get a feel of where the pins would be touching the surface so that I can cad the actual CAM design a lot better with less uncertainties.
Screenshot 2026-06-03 170242.png

I started off with the outer ring, which is the harder one. I began by writing comments on each of the circles and labelling them so it would be easier for me to design which area should rise up and which should fall down. 
Screenshot 2026-06-03 192849.png

Afterwards, since I could not directly sketch onto the cylinder’s outside, I had to calculate a long strip, visualizing the cylinder is laid flat. This way, I can cad the designs onto that and the use the Wrap tool to wrap the extrude around the cylinder.
Screenshot 2026-06-03 192818.png

However, this did not make it any easier. As you can see, there are so many dimensions labeled out (partly because I forgot I could pattern the sketches so I lwk just copied and pasted all of them). But it turned out great. I sectioned off each area/circle with its own construction rectangle and went to work. I used conic arcs to make smooth ramps and inclines for the pins to run on. I further smoothened it later with fillets. This way, there will be minimal effort for the pins to move along the CAM. After wrapping around, the CAM looked good and although wonky, it should do its job.
Screenshot 2026-06-03 201849.png

I also made the ends of the pins thinner so that it can better fit into the CAM and not get stuck in it. Making it smaller also ensures only one point of contact at all times. Two points of contact will likely get the pins stuck and the CAM jammed. 
Screenshot 2026-06-03 201932.png

Next, I did the same with the inner CAM. Since this one only had 4 possible orientations, it was a lot easier to design. I did the same routine/process as the outer CAM, just a lot less complicated.
Screenshot 2026-06-03 213512.png

In the end, I got two finished designs of the CAMs needed for a single braille cell. But since they are inside each other, a problem would be to how to operate each with a servo. I was thinking, since the inside one is surrounded by the outside, the servo has to be from the bottom, so I can either directly design it onto the servo, or I can link them with bevel gears to put the servo at an angel if I liked. The outside CAM was originally hard to think of a design, but I realized I could simply just create a gear pattern on its lower end and also gear a servo next to it. This helped give me a goal for tomorrow.
TLDR: I designed the physical inner and outer CAMs.
Screenshot 2026-06-03 230340.png

NOTE: Also oops, I accidentally named one of the timelapses (inner CAM design) 6/2 instead of 6/3.

### Recording Links

- https://lookout.hackclub.com/api/media/17b43fd1-0139-49f8-83d7-cb27872353d7/video.mp4
- https://lookout.hackclub.com/api/media/06e3b5d5-5656-443d-a121-36fdcbf41531/video.mp4

## Entry 3
- ID: 11789
- Author: kevinkunzhong
- Created At: 2026-06-05T07:02:50Z

### Content

Today, I first tried visualizing my CAM mechanism in an assembly to make sure it can rotate and the pins are able to slide up and down and contact the CAMs properly. I tried making it be able to move and all with the slider mates and revolute mates but I couldn’t get the tangent mate to work since the CAM is not a swept shape. I tried many different ways to get around this but in the end it just didn’t work so I just manually visualized it :) . 
Screenshot 2026-06-04 113018.png

Next, I made the CAMs actually be able to rest on something and not just be floating around. I am trying to finish up my cad today. I made it so that the CAMs will be able to slide into each other and essentially use each other to guide themselves so they keep in position. I did this by making a slot in the bottom CAM for the top CAM to slide into so it is resting on top of it. This way, I don’t need any complicated bearings and things for them to rotate. I also made the tolerances were good so they can actually spin without friction.
Screenshot 2026-06-04 234724.png
Screenshot 2026-06-04 172254.png

Next, I generated all of the gears I need to make sure my servos can move the CAMs. I did this using a featurescript in Onshape to generate the gears and then attached the gears to the CAMs to make them a single part using a bore hole and the boolean feature. This makes sure the parts print together and they move as a whole in real life. Then, by using the same module dimensions for the gears, I geared the gears in a 3:2 ratio to translate the 180 degrees of rotation in the servo to 270 degrees in the CAM. I did this for both CAMs and also attached the gears onto the servos. For the gears on the servo, I also made custom servo splines to directly attach the gears onto the servo. This is because it will be more stable.
Screenshot 2026-06-04 165838.png

Then, I did a LOT of research on what electronics I should use. I know that I will need a camera that will translate the irl letter to braille on the braille cell so I needed a camera. I started with that and found that I can use a raspberry pi to run it as well as the computer vision code. I then went around, since it is my first time working with electronics, finding the good raspberry pi and decided on the 5 with 4GB of RAM as recommended by people online. Then, it was time for the servos and I had to find somewhere to run them. I found the adafruit pca9685 which helped manage all my servos without connecting them directly to the raspberry pi and potentially frying and crashing it during running. After that, I learnt a little bit about how each of these things attach to one another as well as the wires I need, as well as the different cables, power supplies, terminal blocks, etc. After learning all this, I was finally ready to CAD all of these electronics into Onshape and create custom mounting places for them on my project. 
Screenshot 2026-06-04 231530.png

TLDR: I finished cadding the gears for the CAMs, attached to servos, and researched about electronics I need.

### Recording Links

- https://lookout.hackclub.com/api/media/d6fa8885-6585-4d31-95a2-32a82572b36e/video.mp4
- https://lookout.hackclub.com/api/media/9060bb9c-0a13-41d8-80d9-0e8b3007a301/video.mp4
- https://lookout.hackclub.com/api/media/66f0dd8d-9adf-4a04-9a20-dd9096727c5d/video.mp4
- https://lookout.hackclub.com/api/media/579aa234-61f3-48e2-aaf2-f54608690615/video.mp4

## Entry 4
- ID: 12005
- Author: kevinkunzhong
- Created At: 2026-06-06T06:52:10Z

### Content

Today, I focused on mounting all of my electronics into my project. I looked at the 3D model of the electronics and made mounting areas, spacers, and plates according to their measurements with also a little bit of wiggle room in order for the wires and other stuff to pass through. I also stacked my pca board and the raspberry pi on top of each other to save space and ensure that my project fits inside a small box.
Screenshot 2026-06-05 112508.png

One part of the project that I was very proud of was my camera mount. I don’t know, I just felt very creative at the moment and so I just created a very creative and cool camera mount that is also very effective, avoiding all the extrusions in the camera board.
Screenshot 2026-06-05 114437.png

After I have my electronics mounted, I started to stabilize the servos. I made very long pillars on the insides of the servos to prop them up, as well as including a screw hole in the center of course. On the outsides. I used a sort of half arc design to keep the mounts compact but effective. I also made it a two in one type of thing and made it so that it can not only hold the servo but also act as a wire guider to guide the servo wire and ensure it does not get caught in the gears. This leads me to my next design, a simple curved wall between the gears and the electronics. Since there will be a lot of wires, in order to make my design compact, I need to keep the electronics close to the gears. But that risks the wires getting caught. Therefore, the easiest solution is just to create a wall between them, which is what I did. 
Screenshot 2026-06-05 131453.png

Then, I started to make the walls and the actual box that will contain all my important parts. But the wall is still equally important. I made it so that there are holes for the necessary components such as the camera, and the areas to plug in my external power supplies. I also made the wall relatively compact to keep the entire project compact.
Screenshot 2026-06-05 155511.png

I also sectioned the walls and roof into different parts to make assembling it as well as assembling the inside components a lot easier. I put holes in each part so I can easily assemble it later with screws. Now it is like building lego. I also extruded a bit more for the box since I learned that you should have a few mm of tolerance on each side for screw holes and I didn’t have that before; this made it more sturdy. Finally, I realized I should add a button at the top to take pictures to translate instead of analyzing live feed so I added that into the top portion of the roof. I also found a button online for sale which I can directly plug into the raspberry pi without any external breadboards and stuff like that.
Screenshot 2026-06-05 173906.png

Finally, I added some finishing touches to my project and colored the project how it will be when I 3D print it. I also spent some time adding some cool designs as well as more braille on the outside for ease of use (but also for aesthetic purposes). Now it looks very cool!
Screenshot 2026-06-05 220245.png

TLDR: I attached the electronics, made mounts for everything, made the actual box, and designed it.

### Recording Links

- https://lookout.hackclub.com/api/media/847e5e3d-78bb-401d-ba62-6a97dd3baa10/video.mp4
- https://lookout.hackclub.com/api/media/56dfc40b-1351-43d3-9070-d5f5969ceb90/video.mp4

## Entry 5
- ID: 12208
- Author: kevinkunzhong
- Created At: 2026-06-07T05:45:17Z

### Content

Today, I finished up my cad by adding some finishing touches such as the holes which will help for an easier assembly. I also finished creating my assembly, taking all of the parts and electronics and put them together using mates. I also put revolute and gear mates on the CAMs to better help visualize them. I also researched on which screws to use for which electronics and also imported and took note of the different screws to use. I made sure to use the correct ones so my model will be put together properly. However, while I was doing this, I encountered a problem. The PCA board’s part model was not coming out properly so I had to re-cad its model based on the dimensions in order to import it into my assembly. Additionally, I also found the backlash dimensions for the gears and added in a bit to ensure the gears turn smoothly with minimal friction. I also organized my part studio features a little bit because it was getting out of hand. In the end, I finished putting screws on everything and mating all components together for my project model.
Screenshot 2026-06-06 220110.png

I also began working on my zine, brainstorming its theme. I know that I need a QR code to my repository as well as a few pictures and descriptions of my project. Since I named my project Tiresias’ Box, I was thinking to have a mysterious, Greek mythology type theme for my zine. I wanted a dark green aura and mist for the color scheme. I also wanted to draw a cartoon picture of Tiresias very auraful and holding my project.
Screenshot 2026-06-06 223742.png

I also started my README, researching a little bit on what I should include for a hardware project. I created a document that listed out my stuff and thought process and what components to add to my README. I started looking at other people’s READMEs and found some inspiration on what to put into mine. I did a general outline on what to write today and I will start writing soon.
Screenshot 2026-06-06 223926.png

Finally, I did some testing with my 3d CAM model for the first time! I went in very optimistic but my first model did not come out good. My pins kept jamming in the CAM and some tolerances were not good so the CAMs could not spin properly. I printed my models using a 0.2 nozzle and the finest settings in my Bambu slicer so my models overall came out very nice. This is so that my curves for the CAM are as smooth as possible, as well as my layers. However, I did also figure out my pins were hard to put into their slots so I needed to also widen them a little bit. Overall, the first model was not bad. 
v1 testing.jpg

TLDR: I made my CAD assembly, started my zine and README designs, and tested my first CAM model. 

### Recording Links

- https://lookout.hackclub.com/api/media/7246bb88-8616-46b3-b0ab-54a43fc396ca/video.mp4
- https://lookout.hackclub.com/api/media/76c34f42-1cf1-4e91-8394-28b946cc46d6/video.mp4

## Entry 6
- ID: 12433
- Author: kevinkunzhong
- Created At: 2026-06-08T05:06:19Z

### Content

I was honestly a bit tired today so I didn’t do much. But I still did as much as I can lol. I did lots and lots of 3d printing today, testing out my CAMs and pins, which are the most important parts. I printed using the most fine settings to get the best layers and most precise parts. I tested and tweaked multiple different measurements for the CAM such as making it half as tall, which made my CAM much smoother since the pins don’t need to travel that much distance now. It also jams a lot less. Another tweak I made to make it jam less is by making the pin tip a bit bigger since the original point is very small and sometimes get caught between the layer lines of the print. Yes very annoying. I also made the holes for the pins ever so slightly bigger to make it have less contact with the pins. Overall, everything is coming together very nicely actually. I also made the pins taller since I realized there is a bit of room and the taller they are, the easier they are to feel irl so yeah very nice!
Screenshot 2026-06-07 190542.png
Screenshot 2026-06-07 192345243.jpeg

I also added a bit more design to my outer box to indicate where the front is and which side of the box should be facing up. This makes this more aesthetic lol but also contributes to the practicality.
Screenshot 2026-06-07 190227.png

I also created my BOM, which includes every single part that is needed for my project. I also added in some kits for screws and solders since I don’t have any of those parts and someone who is in my situation probably also doesn’t have them. I also included wires I need to solder or cut for my project as well as connect to my electronics. However, no matter how hard I scour online I can’t find sellers that sell only singular units so they are all in like “bulk” but not really “bulk”, just more than I need but I made the sure prices are cheap, please please. This is also the same for the servos. I also researched which servos to use and digital was my best bet for precision turning. However, the least I can find for digital servos is like 3 and I only need 2 so that was annoying but it is cheap I promise :,)
Screenshot 2026-06-07 220046.png

TLDR: Lots of printing and testing, tweaked the CAMs, pins and holes, added more design to the outer box, created BOM.

### Recording Links

- https://lookout.hackclub.com/api/media/31a8774f-5bac-42b9-b532-be0d844d5105/video.mp4

## Entry 7
- ID: 12698
- Author: kevinkunzhong
- Created At: 2026-06-09T06:29:41Z

### Content

Today, I did a lot of research for how to write code for the Raspberry Pi and the Adafruit PCA9685. I learned a lot about all the libraries I needed to use as well as the functions and syntax for coding for Raspberry Pi using Python. For my project, I needed to translate irl words that blind people cannot see, into braille for them to read. Therefore, I figured out how to code my raspberry pi camera and using easy OCR to take a picture on the raspberry pi and then analyze that picture for text. OCR is a computer vision library like OpenCV to detect text in real life and returns it as character text on the computer. This allows me to be able to read text in the real world and convert it to strings that my code can read. I incorporated the easyocr Python library for this project. I wrote code for my servos, camera, and main execution branch in separate files, each initializing its own things. I finished writing the code that initializes the servos as well as functions to move the servos to positions that will pop up certain braille by moving the CAMs. However, the positions still need to be tuned as I do not have the parts to build this yet. I also wrote a custom function that moves the position servos gradually to the positions since the pins might jam or fling out if the CAM moves very quickly. Additionally, I wrote code for the camera, adding in functions to take a photo, and then further analyze the photos for text to return back to the main execution branch. When taking the pictures, it saves as a jpg to the Raspberry Pi but to save storage, I delete the image files after analyzing as they will be no more use. Finally, I made a custom logic loop for a button which takes a picture every short press but turns off the code running and the camera for a press that lasts longer than 3 seconds. This is pretty much it for the coding portion of my project and I was happy I finished it all today.
Screenshot 2026-06-08 230851.png

I also began to work on writing setup guides to the software and hardware processes. I made sure to write them as detailed as possible as well as include external resources for people like me, who are complete beginners, to be able to follow clearly. I was also learning along while writing these setup guides so they may be a bit wonky but I will definitely fix that tomorrow. I also tweaked my CAD assembly a little bit since my gear relations were not working and I could not for the life of me figure out why even though they looked fine in the preview; they just stopped working as soon as I confirmed them. So I just removed them entirely, I know the gears work anyways lol.
Screenshot 2026-06-08 230832.png
Screenshot 2026-06-08 230937.png

TLDR: I coded everything and started writing the setup guides.

### Recording Links

- https://lookout.hackclub.com/api/media/83b3f5b6-0a11-41bf-927c-63a133a9216c/video.mp4
- https://lookout.hackclub.com/api/media/6f6a3f1d-f7f7-4dd8-b0e9-6db8cc77599b/video.mp4

## Entry 8
- ID: 12949
- Author: kevinkunzhong
- Created At: 2026-06-10T06:38:05Z

### Content

I finished all of the setup guides and finished everything that is required in the repository today. I made sure that the setup guide and the README were very well detailed and complete beginners would be able to follow them very easily. This was easy to test since I am a complete beginner and if I could follow them well, I knew that other people like me could as well. I spent a lot of time making all the files, guides, and the main README as nicely formatted as possible to make everything look extremely polished. I also added a lot more to the README than the required materials since I believe it encompasses my project a lot more and allows people to get a more descriptive grasp on my project, such as the highlights, the future, and the hardware section. I got these inspirations from the many READMEs of many other repos that I came across. 
Screenshot 2026-06-09 114617.png
Screenshot 2026-06-09 232442.png

I also redesigned the servo gears a bit and added a little overhang at the edge of the gears to help keep the CAM gears in place. This ensures that as long as the servo gears are attached properly to the servos, the CAM gears will not pop out of place and continue with its smooth motion with the servo gears. This also makes sure the CAM gears do not misalign that easily if the box is tilted or maybe even flipped upside down.
Screenshot 2026-06-09 114557.png

I also continued on beginning on designing my zine today. I did start earlier but I wanted a better design. Since I had a Greek prophet’s name for my project, I was thinking of a Greek mythology theme. But since my project uses white and orange, I had to either go with a black orange or white orange theme. And I chose black orange. I was genuinely out of ideas for the day and I started with a very simple background for my zine and generated my qr code. I also had a rendered picture of my finished assembled 3D model to be the main graphic in the center.
Screenshot 2026-06-09 232213.png

TLDR: I finished everything in the repo, tweaked the gears, and I started to create a zine.

### Recording Links

- https://lookout.hackclub.com/api/media/d6c820fa-8891-49f7-b0c0-9bd89653d141/video.mp4
- https://lookout.hackclub.com/api/media/66f1351b-bd33-4efe-a607-abbc8ac0d33f/video.mp4

## Entry 9
- ID: 13163
- Author: kevinkunzhong
- Created At: 2026-06-11T04:43:59Z

### Content

Today I worked on the final part of my Fallout submission, the zine. I was initially thinking to actually draw Tiresias and him holding up my project but I tried for a while and it was honestly too complicated (and I don’t know how to draw so drawing humans was extremely challenging). So, I just went with a very simple “design around my project” approach and just made my zine visually appealing (at least I think) by using a lot of colors and other hand drawn designs! Since my project is white and orange, I was thinking of using a orange theme to create my designs. I honestly don’t know my thought process behind my design I just went with the flow and tried out a lot of new things and eventually this is what came out. I also went into my cad and brought out some parts, especially the custom CAM and made them transparent background like my project picture. After adding them to my repo, I think I am done with my design submission! I am so happy that I finished designing this project and I really hope my design gets accepted.
Screenshot 2026-06-10 182337.png


TLDR: I finished my zine and everything I need for submission.

### Recording Links

- https://lookout.hackclub.com/api/media/8ef3fb35-5e08-4fac-b283-3ef1e938641a/video.mp4
- https://lookout.hackclub.com/api/media/4bb23151-9a4d-4088-9f98-a242de43eb11/video.mp4

## Entry 10
- ID: 13394
- Author: kevinkunzhong
- Created At: 2026-06-12T06:45:40Z

### Content

Today, I added onto my initial code and added in the support for translating Chinese to English. I used the Python library deep_translator to have a quick and efficient way of translating from other languages to English without having to sacrifice the precious RAM that I need for OCR. I made new functions in my code that essentially takes the extracted text from OCR and translates it into English to then translate into braille. So it is basically adding a layer of translation! I added this because I am Chinese, and also Chinese is one of the most widely spoken languages with English so adding support for it is a must imo. However, I don’t want to run unnecessary models or libraries since I already have so little RAM. So, I also added in a toggle between English and Chinese to English with the button and changed the timing a little so the button can take a picture, toggle language, and turn off the camera/code. I also updated my README and installation steps due to this change. Furthermore, I also researched more on the memory usage of EasyOCR and find that it was very scary and actually does use quite a lot of RAM for my purposes. Therefore, I looked into a quantized model that lessens the precision and helps with the memory and latency, especially with using a CPU and no GPU for RPI. One more thing I added is the support for numbers in the braille as well and I found that my braille cam actually works for numbers as well so I added that into the positions dictionary and the extracting text code. 
Screenshot 2026-06-11 234223.png
Screenshot 2026-06-11 234201.png
Screenshot 2026-06-11 234135.png

TLDR: I added in support for Chinese to English translating, added in numbers for braille, optimized EasyOCR model.

### Recording Links

- https://lookout.hackclub.com/api/media/11503b03-8c5a-4e3a-a15b-e0e48f8e22f6/video.mp4

## Entry 11
- ID: 13653
- Author: kevinkunzhong
- Created At: 2026-06-13T06:21:34Z

### Content

Today I officially started the build process of my project and it started off fairly well. Almost all of my parts have arrived so I was able to begin putting everything together and testing up my servos. I also got my Raspberry Pi so I was able to do everything with the software setup and that went somewhat smoothly. During the process, I encountered an issue where the Raspberry Pi ran out of storage to install the easyocr package but that was very confusing since it definitely had enough storage for that. However, after looking into the problem more, I realized that the Pi was using its RAM drive to help install the packages, quickly filling up the 2GB space. Therefore, I had to force pip to use the main drive to install it. Since I would assume this problem would also occur with others, I included the steps I used to solve it in the revised software setup guide.
Screenshot 2026-06-12 184528.png
Screenshot 2026-06-12 231338.png

Next, I went on to solder the PCA9685. This was my very first time soldering so I was very careful and watched a few tutorials before I started. My dad was also watching next to me in case I burnt myself. I took a long time to get the hang of soldering and melting the solder wire cleanly on the pins but eventually I got it and it was actually quite fun. As I tried not to burn myself, I finished up with the soldering and got all the pins and the terminal block to be on the board. I then stripped some of the 20AWG wires and connected the terminal block to the power adapter. Now, I am done with the PCA9685 setup.


Finally, I also tested the servo code as well as the gradual movement code and tuned the delay time to be about 0.01 seconds. This allowed me to have a smooth transition from position to position. I connected all the wiring to the Raspberry Pi and all the power supplies and the servos and this was my first official test (excluding the camera). Everything worked very well but the only thing was the servo positions was not 180 it was more like 120 but that should be fine.


TLDR: I setup the Raspberry Pi software, I soldered the PCA9685, I tested the servo code with nearly everything setup.

### Recording Links

- https://lookout.hackclub.com/api/media/8df4c368-a249-4b13-a1bb-eed6c1fdeb17/video.mp4
- https://lookout.hackclub.com/api/media/155d09e0-21f7-4988-b6ee-0d9a9449b5f4/video.mp4

## Entry 12
- ID: 13828
- Author: kevinkunzhong
- Created At: 2026-06-13T21:43:07Z

### Content

Today, I tested the servo gears but then I realized the custom servo spline for the micro servo was too precise to be printed properly with the servos so I just decided to change my design and embed the servo horn that the servos came with into the servo gears. Along with this, I also tested the tolerances of the holes the screws would be screwed into and I resized a lot of the holes. Using a caliper and the servo horn in real life, I measures its dimensions and created an area for it to be embedded inside of the servo gears. This works because it is rotational motion and the servo gear is connect to the servo horn still since it has a hole at the top in which the servo screw is gonna be screwed in.
Screenshot 2026-06-13 112331.png

Another thing I added to the cad is a ventilation system (aka just a few holes) under the raspberry pi to allow it cool down better. This allows it to cool better since I noticed that it heated up quite much when running some test code yesterday. Hopefully this will allow it to run better. This also uses less filament lol. 
Screenshot 2026-06-13 125155.png

Afterwards, all of these changes had me to change the hardware setup instructions as well as update the cad files in the repo.

TLDR: Embedded servo horn for servo gears, resized holes, added ventilation.

### Recording Links

- https://lookout.hackclub.com/api/media/98a2ab8f-967d-4abf-babc-359203d88b2d/video.mp4
- https://lookout.hackclub.com/api/media/97477996-9b61-456d-8456-5f9eb3d7c2c8/video.mp4

## Entry 13
- ID: 14473
- Author: kevinkunzhong
- Created At: 2026-06-16T06:46:28Z

### Content

Today I worked on many different things, a lot of which are just testing my components and building. I first finished printing out everything I needed, as well as doing the manual filament color changing since I don’t have an AMS soo yeah. I did not record myself 3D printing btw lol. Anyways, the colors came out very nice and while I was doing that, I also had to tweak a few more hole tolerances for my prints and finally everything is coming together very nicely with the screws. 


For the roof print, I had a very fun time taking off all of the supports since it was a very weird print to orient in the slicer and the colored side had to face up so that was very fun. Another part is the embedded servo horn which I tested and it worked out amazingly, the tolerance was perfect first try and I was very proud of myself for that.


I also tested a few things with my code. I tested my easyocr and it worked out perfectly. There was a few hiccups and the red text was a big scary but I was able to get it working with a few tweaks such as flipping the camera orientation in the code since I did not realize that the camera would be mounted upside down. I also changed some of the timing since the camera needed a bit more time to focus than I thought, but it was fine afterwards. I tested the camera with a few different lines of words and my pipeline was able to perfectly split the words into characters nicely. I was also surprised and very proud, and also anxious since I didn’t know what to do if it failed lol.


Finally, I also tested the code for the button and it worked fine so I was happy to finally start building. I used my hardware setup guide, to screw everything in and plug the wires in where they are supposed to go. This process was somewhat smooth but sometimes my hands get sweaty and since I am using M2 and M2.5 screws, the allen key is very small and it slips a lot and I get very annoyed. But otherwise, the building process I would say is half complete and the only thing left is to tune the servo positions and screw the walls in.


TLDR: I tested the code, and I started building.

### Recording Links

- https://lookout.hackclub.com/api/media/c806b337-4877-4848-b1ce-7aa41e5820a0/video.mp4
- https://lookout.hackclub.com/api/media/aa9fbc9a-7178-413d-bf52-5835d92567af/video.mp4

## Entry 14
- ID: 14705
- Author: kevinkunzhong
- Created At: 2026-06-17T06:36:00Z

### Content

Today I finished up assembling the whole thing and started tuning the positions of the pins. However, during the process, the servo gears that are colored accidentally got snapped so I had to use my red ones, which are the exact same thing but a different color. Along with that, I finished printing the pins and I also tested my code for the pins. I also retuned the speed constant at which the gears would be rotating to help smooth out the motion of the pins. I assembled the walls, and securely attached all parts of my project. Tuning tins took a long time since you needed to make sure the positions are correct to a very accurate degree so I usually had to go degree at a time for the rotation angle. This took up the bulk of my time. Other than that nothing much really happened. I really hope I can finish tuning tomorrow at test my full code and then hopefully finish my project tomorrow!



### Recording Links

- https://lookout.hackclub.com/api/media/7dbc6cdd-b765-40c9-b0fc-50a6e47d394b/video.mp4

## Entry 15
- ID: 15138
- Author: kevinkunzhong
- Created At: 2026-06-19T03:16:02Z

### Content

Today and yesterday, I finished testing everything and although the cv on my project takes some time to process (since I am running on a Raspberry Pi), MY PROJECT FINALLY WORKS!! This is actually so surprising and I feel so proud because I genuinely didn’t take many attempts to test my project. My final attempts were just used in the video I made later on explaining this project. I made some final adjustments to my project, such as adding barriers to the cams (and I updated the repo :) ) which made my cams and pins even smoother and now they can even run at full speed with the rotating servo without jamming one bit. However, I still set the speed a bit lower just to be safe (and for aesthetic purposes since making it move slower makes it seems so much more cooler). I also finished tuning all the positions of the braille pins for every single letter and number. I didn’t do it for every letter and number, I just did it for every possible combination and then combined the inner and outer cam values to make up the values needed for each letter.
Screenshot 2026-06-18 200948.png

I tested my chinese translator as well by typing and printing out a sheet of paper with chinese characters on it and IT WORKED! First try lol. But it was so cool watching my project in action and working properly after all the time I spent making it. After my final bits of testing and confirming my project works 100%, I started creating the video used to showcase my project, making it actually shipped. I did some video planning, taking some of the text I wrote for my repo and making it into a script for me to say. I also printed out a few testing materials (text) to show off on my video. Later, I started filming the actual video and then after filming, I started putting the video together on capcut. Capcut was so laggy and my video was corrupted the first time around and I COULD NOT FIND THE VERSION HISTORY. So I had to salvage my video and that took some time but in the end, it came out how I wanted it to. I genuinely did not know I could create something like this in 14 days and I want to thank fallout for giving me this opportunity. I am so excited to finish! Please go watch my demo video, it has a lot of cool clips and stuff :)))))


TLDR: FINAL SUCCESS

### Recording Links

- https://lookout.hackclub.com/api/media/6ca60236-953b-4222-a0a4-50c2169f14e2/video.mp4
- https://lookout.hackclub.com/api/media/41a01b6f-2deb-4bb6-ae12-ca7666a528d8/video.mp4
- https://lookout.hackclub.com/api/media/dd32f75c-4f4d-4a17-a409-42afcd3b34cb/video.mp4
- https://lookout.hackclub.com/api/media/b6a09a5d-43a2-489e-99c0-87a0cfdae077/video.mp4
- https://lookout.hackclub.com/api/media/b85b4b3b-036c-490d-896f-32da0922bc62/video.mp4
- https://lookout.hackclub.com/api/media/daee17cc-462d-4080-af52-c1dd61495655/video.mp4

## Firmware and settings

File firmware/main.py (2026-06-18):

from gpiozero import Button
import time
import camera
import servos

button = Button(5) #pin 5 but could change
servos.initial_pos()

english = True
status = True #true for on
pressed = False
photo_taken = False
start_time = time.time()
duration = 0
wait = 3
letters = []

while status:
    if button.is_pressed and not pressed and not photo_taken:
        pressed = True
        start_time = time.time()
    elif not button.is_pressed and pressed and not photo_taken:
        pressed = False
        duration = time.time() - start_time
        if duration >= 6:
            status = False
        elif duration >= 3:
            english = not english
            time.sleep(1)
        else:
            camera.take_photo()
            photo_taken = True

    if photo_taken:
        if english:
            letters = camera.analyze_photo()
        else:
            letters = camera.analyze_chinese_photo()
        if letters != []:
            for i in range(len(letters)):
                servos.move_to_letter(letters[i].lower())
                time.sleep(wait)
            letters = []
        photo_taken = False

camera.stop_camera()
servos.off()

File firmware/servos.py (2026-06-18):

import time
from adafruit_servokit import ServoKit

kit = ServoKit(channels=16)

#start positions, tune later
cur_pos_inner = 180 #servo port 0, inner
cur_pos_outer = 180 #servo port 3, outer

inner_servo_positions = {
    "a" : 50,
    "b" : 170,
    "c" : 50,
    "d" : 110,
    "e" : 110,
    "f" : 170,
    "g" : 150,
    "h" : 150,
    "i" : 170,
    "j" : 150,
    "k" : 50,
    "l" : 170,
    "m" : 50,
    "n" : 110,
    "o" : 110,
    "p" : 170,
    "q" : 150,
    "r" : 150,
    "s" : 170,
    "t" : 150,
    "u" : 50,
    "v" : 170,
    "w" : 150,
    "x" : 50,
    "y" : 110,
    "z" : 110,
    "0" : 150, 
    "1" : 50, 
    "2" : 170, 
    "3" : 50, 
    "4" : 110, 
    "5" : 110, 
    "6" : 170, 
    "7" : 150, 
    "8" : 150, 
    "9" : 170
}

outer_servo_positions = {
    "a" : 170,
    "b" : 170,
    "c" : 75,
    "d" : 75,
    "e" : 170,
    "f" : 75,
    "g" : 75,
    "h" : 170,
    "i" : 120,
    "j" : 120,
    "k" : 162,
    "l" : 162,
    "m" : 158,
    "n" : 158,
    "o" : 162,
    "p" : 158,
    "q" : 158,
    "r" : 162,
    "s" : 90,
    "t" : 90,
    "u" : 40,
    "v" : 40,
    "w" : 110,
    "x" : 83,
    "y" : 83,
    "z" : 40,
    "0" : 120, 
    "1" : 170, 
    "2" : 170, 
    "3" : 75, 
    "4" : 75, 
    "5" : 170, 
    "6" : 75, 
    "7" : 75, 
    "8" : 170, 
    "9" : 120
}

# move to english letter and numbers only, no need to worry about translations here

def move_to_letter(letter):
    position(0, inner_servo_positions[letter], 0.005)
    position(3, outer_servo_positions[letter], 0.005)

#gradually moves servo
def position(servo_num, end_pos, delay):
    global cur_pos_inner, cur_pos_outer
    start_pos = 0
    if servo_num == 0: 
        start_pos = cur_pos_inner
    elif servo_num == 3: 
        start_pos = cur_pos_outer

    step = -1
    if start_pos < end_pos:
        step = 1

    for pos in range(start_pos, end_pos+step, step):
        kit.servo[servo_num].angle = pos
        time.sleep(delay)

    if servo_num == 0: 
        cur_pos_inner = end_pos
    elif servo_num == 3: 
        cur_pos_outer = end_pos

#should run this first
def initial_pos():
    global cur_pos_inner, cur_pos_outer
    kit.servo[0].angle = cur_pos_inner
    kit.servo[3].angle = cur_pos_outer

def off():
    kit.servo[0].angle = None
    kit.servo[3].angle = None

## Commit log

2026-06-10 Pushing all the code files, basically just all dfsf
    [BOM.csv, base.step, braille pin 1.step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]
2026-06-10 read me edits
    [BOM.csv]
2026-06-11 Include wiring diagram in hardware setup guide
    Added a wiring diagram reference to the hardware setup instructions.
2026-06-11 Fix wiring diagram image path in hardware_setup.md
    Updated image path for wiring diagram in hardware setup documentation.
2026-06-11 Update button mounting instructions in hardware setup
    Clarified instructions for securing the button on the roof.
2026-06-11 Update hardware_setup.md with BOM reference
    Added a reference to the BOM for project assembly.
2026-06-11 Update BOM path in hardware setup documentation
2026-06-11 Fix BOM file path in hardware setup instructions
    Corrected the path to the BOM file in the hardware setup documentation.
2026-06-11 Fix BOM path and clarify hardware setup instructions
    Updated BOM reference path and clarified hardware setup assumptions.
2026-06-11 Fix BOM link in hardware setup documentation
    Updated BOM link to correct relative path.
2026-06-12 updated BOM
    [BOM.csv]
2026-06-13 Revise servo gear and CAM placement instructions
    Updated instructions for placing servo horns and gears in the hardware setup.
2026-06-13 safe power off servos for setup
2026-06-13 updated cad files with new stuff and changes
    [base.step, braille pin 1.step, braille pin 2.step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]
2026-06-14 Update 3D printing instructions for hardware setup
    Added recommendation for 3D printing settings for the base and parts.
2026-06-14 Enhance 3D printing instructions in hardware setup
    Added detailed printing specifications for 3D parts.
2026-06-14 updated cad
    [close wall.step, far wall.step, left wall.step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]
2026-06-15 Add optional Raspberry Pi camera usage instructions
    Added instructions for using the Raspberry Pi camera.
2026-06-15 flip camera orientation
2026-06-16 Fix screw size for Raspberry Pi Camera Module 3
2026-06-17 code changes and others
    [long spacer 1.step, long spacer 2.step, long spacer 3.step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]
2026-06-18 added guide walls for cams, even smoother now
    [inner cam.step, outer cam.step]
2026-06-18 updated smoother roof
    [roof.step]
2026-06-18 updated main assembly step
2026-06-19 updated zine and images for irl and widdened usbc port
    [left wall.step]
2026-06-20 Update README with project details and comparisons
    Revised explanation of the project's unique approach to dynamic braille actuators, emphasizing the use of CAM mechanisms and motor efficiency.
2026-06-20 Revise README to enhance clarity on braille actuator design
    Clarified project differences from existing dynamic braille actuators and streamlined explanations.
2026-06-20 Update README with project details and unique features
    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
2026-06-20 Update README to specify rotating CAM mechanisms
    Clarified the description of the braille actuator cell by specifying 'rotating CAM mechanisms'.
2026-06-21 asd
    Added a note about gluing the button for added security.
2026-07-20 Update print statement from 'Hello' to 'Goodbye'
